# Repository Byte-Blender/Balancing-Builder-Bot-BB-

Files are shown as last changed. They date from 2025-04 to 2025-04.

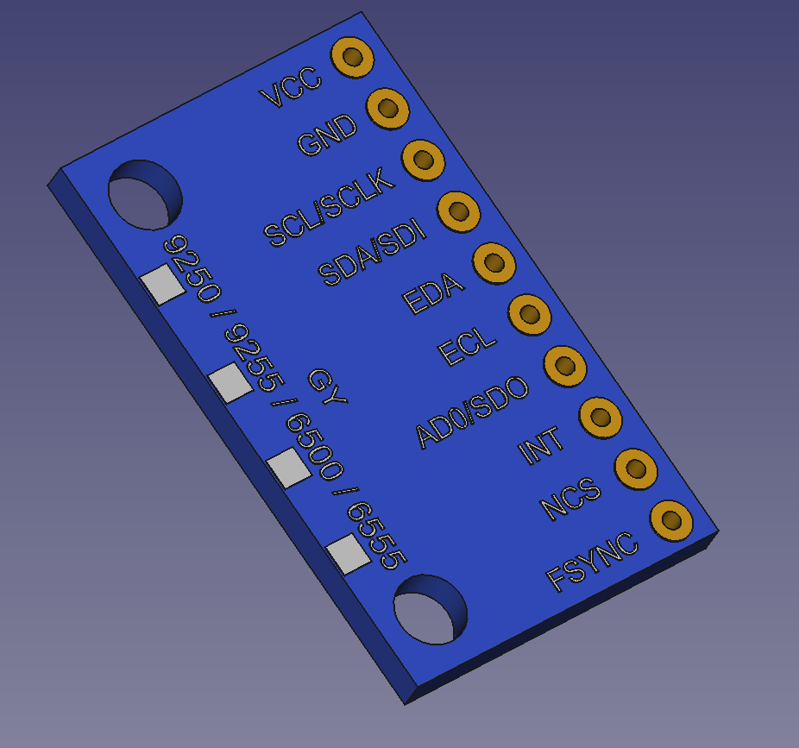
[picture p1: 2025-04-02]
Design files/Full Robot Assembly/Electronics/module-mpu-92-65-1.snapshot.3/mpu9250_bot.png

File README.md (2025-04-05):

# 🤖 Project Documentation: Balancing Builder Bot

**Team ID:** 2286  
**Author List:** Vidhi Singh Rajput, Shreyansh Gupta, Shreyas Rathore, Udit Nayak  
**Theme:** Balancing Builder Bot  
**Competition:** e-Yantra Robotics Competition (eYRC) 2024-25  

---

<h2>🏁 1. Competition Context</h2>

This project is developed as part of the prestigious <strong>e-Yantra Robotics Competition (eYRC)</strong> 2024-25, organized by <strong>IIT Bombay</strong>, under the theme “<em>Balancing Builder Bot</em>”.

e-Yantra is a national-level robotics competition that encourages innovation in embedded systems and robotics by solving real-world problems using hardware-software co-design. The Balancing Builder Bot theme challenges participants to build a robot that:

<ul>
  <li>Balances autonomously using control algorithms</li>
  <li>Navigates to specific checkpoints</li>
  <li>Picks and places objects using a robotic arm</li>
  <li>Interprets and acts on commands in real time</li>
</ul>

This documentation and code reflect our implementation for <strong>Task 2A</strong>, which involves combining balancing control with object manipulation using a pick-and-place arm.

---

## 🧠 2. Project Overview

The Balancing Builder Bot is a two-wheeled self-balancing robot that uses a combination of sensors, motors, control systems, and communication protocols to:

- Maintain an upright posture like an inverted pendulum  
- Move forward/backward based on user commands  
- Pick up and place objects using a servo-based robotic arm  
- Communicate via Bluetooth with external controllers  

---

## 🔧 3. Hardware Components

- **Microcontroller:** Arduino Uno/Nano  
- **IMU Sensor:** MPU6050 (accelerometer + gyroscope)  
- **DC Motors with Encoders** (for feedback)  
- **Servo Motors:** 2 (for arm and gripper control)  
- **Bluetooth Module:** HC-05  
- **Motor Driver Module:** L298N or equivalent  
- **Power Supply:** Battery Pack (7.4V or 11.1V Li-ion)  
- **Chassis:** Custom two-wheeled bot frame with mount for arm  

---

## 📦 4. Software and Libraries

- **Platform:** Arduino IDE  
- **Libraries Used:**
  - `MPU6050_light.h`
  - `Wire.h`
  - `Servo.h`
  - `SoftwareSerial.h`

---

## 🔁 5. Key Functionalities

### 🤖 a. Self-Balancing Using PID

- Reads tilt angle from MPU6050  
- Calculates PID output to control motor speed/direction  
- Maintains upright balance  

### 🧭 b. Position Control

- Uses wheel encoder feedback  
- Enables precise movement forward/backward  

### 💡 c. Bluetooth Command Interface

- Receives instructions like `forward`, `balance`, `arm_up`, `grip_close` etc.  
- Parses commands to trigger corresponding robot actions  

### 🛠 d. Pick and Place Arm

- Gripper and arm are controlled via servos  
- Smooth transition between positions using `moveServo()`  

---

## ⚙️ 6. Control Systems

- **Angle PID:** Keeps the robot upright  
- **Position PID:** Adds positional correction while in motion  
- **Encoder ISR:** Interrupt-driven wheel rotation tracking  

---

## 📡 7. Communication

- **Bluetooth (HC-05)** is used for wireless control  
- `SoftwareSerial` is mapped to analog pins A0 (TX) and A1 (RX)  
- The bot continuously checks for serial commands every 50 ms  

---

## 🧪 8. Testing and Evaluation

- Robot is tested in **CoppeliaSim simulation** first (if available)  
- Calibrated and tuned PID values on physical hardware  
- Passed Task 2A evaluation for:
  - Maintaining balance  
  - Successful pick-and-place  
  - Keyboard-controlled forward/backward navigation  

---

## 🚀 9. Sample Command Flow

1. Robot starts and balances  
2. Bluetooth sends `forward` → Robot moves forward  
3. `arm_down` + `grip_close` → Picks object  
4. `arm_up` → Lifts object  
5. `backward` → Moves to drop zone  
6. `arm_down` + `grip_open` → Drops object  
7. `balance` → Returns to balancing state  

---

## ⚠️ 10. Limitations & Future Scope

- **MPU6050** can be noisy; applying complementary/Kalman filter could improve results  
- **Encoder accuracy** depends on mechanical alignment  
- **State machine** implementation can make behavior more modular  
- Could be extended with **autonomous navigation** using vision or line-following sensors  

---

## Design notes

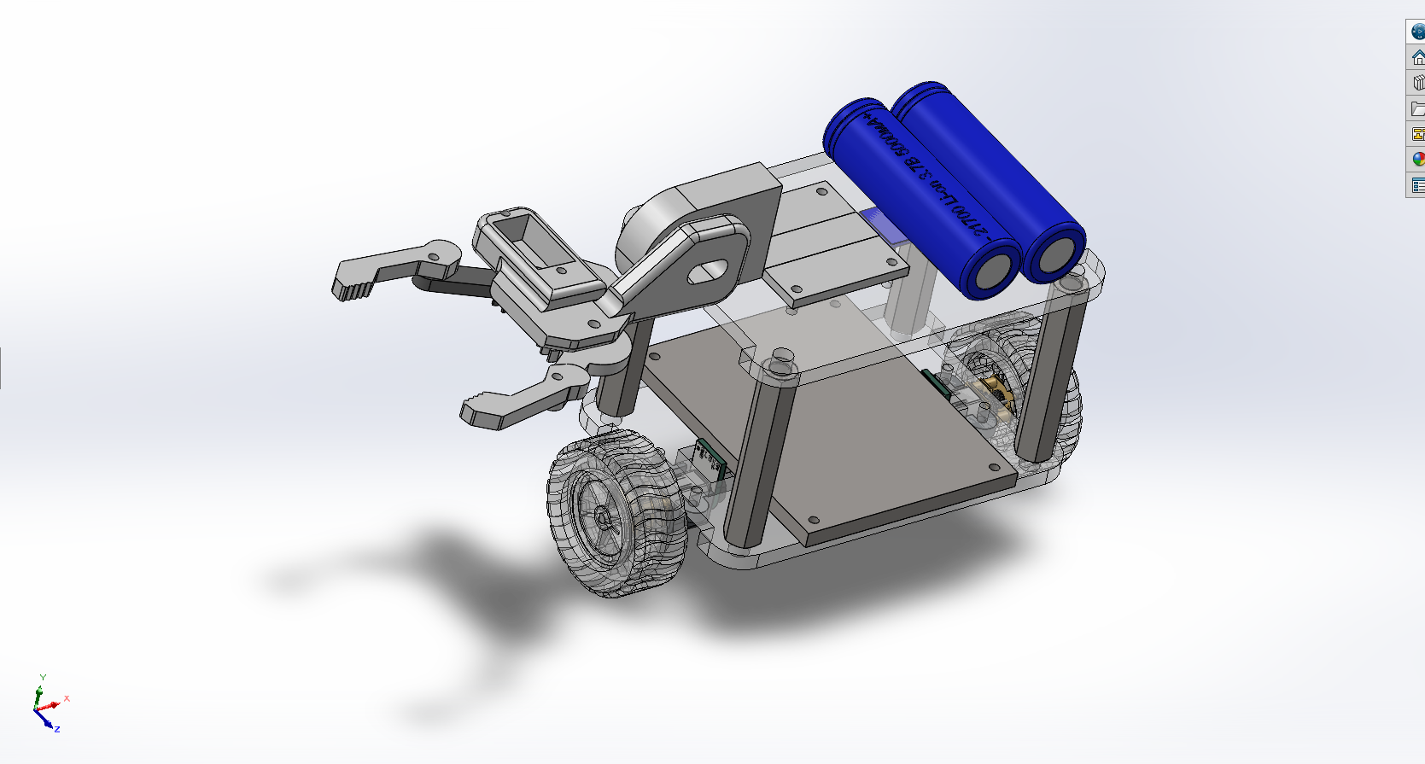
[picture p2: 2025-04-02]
Design files/Screenshot 2025-04-02 233240.png

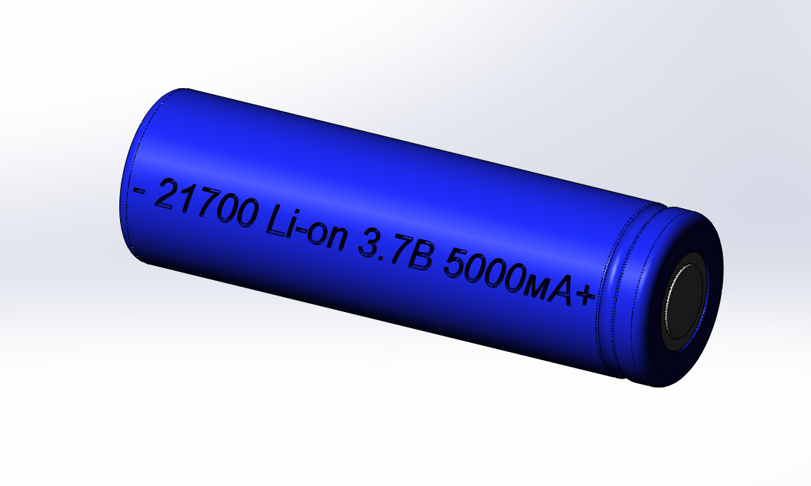
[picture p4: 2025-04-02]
Design files/Full Robot Assembly/Electronics/21700-3-7-5000-1.snapshot.2/Элемент 21700.png

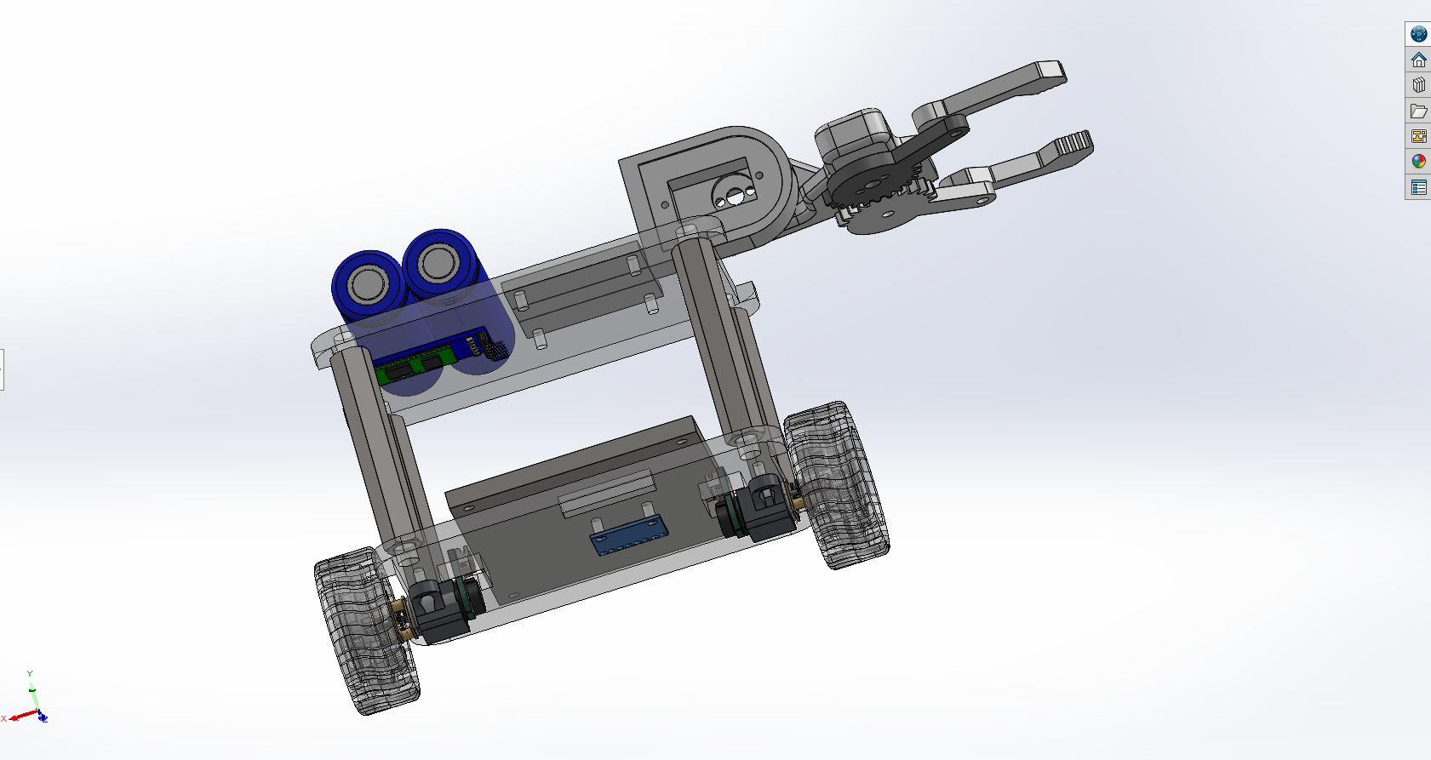
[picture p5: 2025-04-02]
Design files/Screenshot 2025-04-02 233254.png

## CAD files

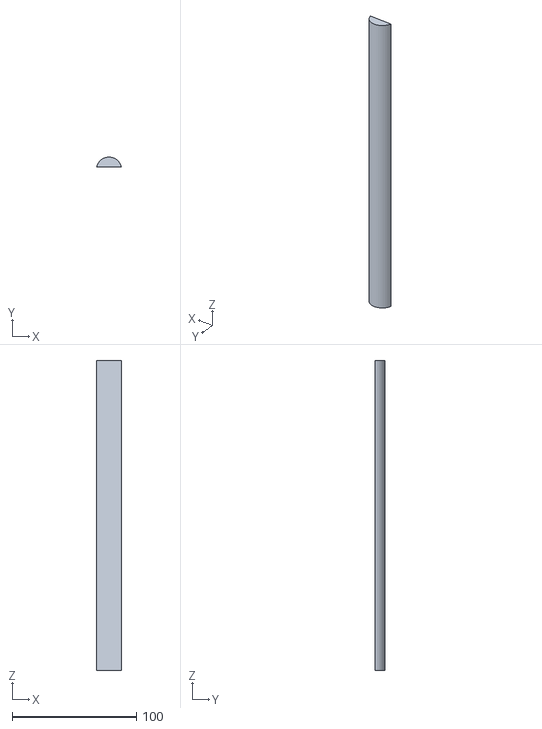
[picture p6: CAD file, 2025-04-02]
Design files/Arena Obstacles/cut/ramp_obstacle.stl
20.0 x 8.00 x 250.0

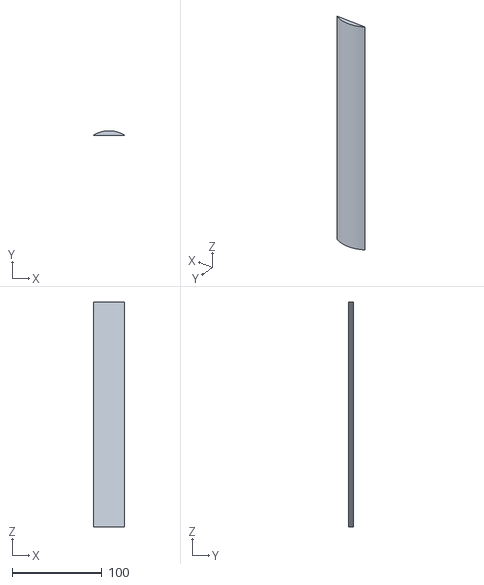
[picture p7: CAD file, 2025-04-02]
Design files/Arena Obstacles/Obstacle_1.stl
35.0 x 5.00 x 250.0

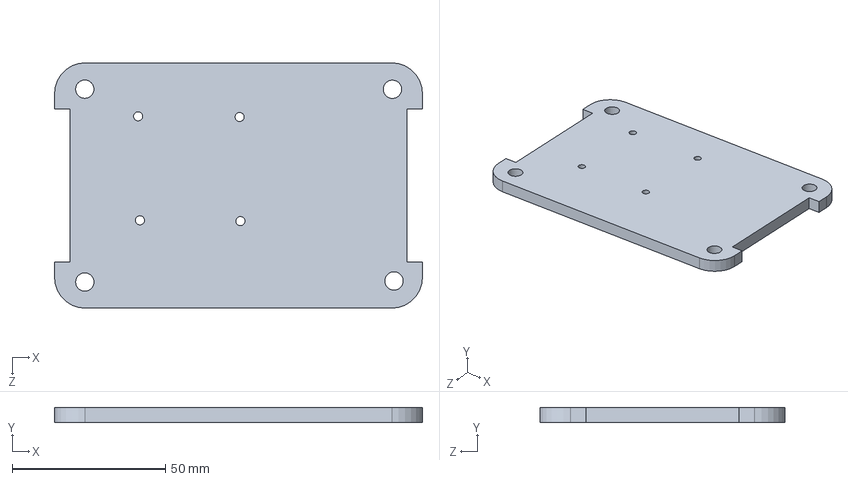
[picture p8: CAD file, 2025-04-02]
Design files/Full Robot Assembly/Body/top.SLDPRT
120.0 x 5.00 x 80.0 mm

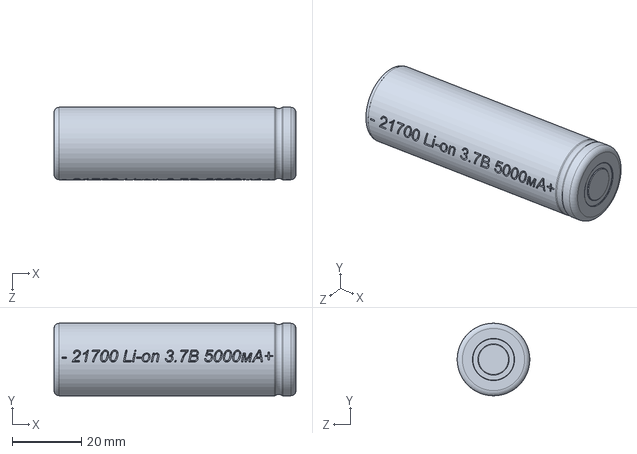
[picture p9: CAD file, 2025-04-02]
Design files/Full Robot Assembly/Electronics/21700-3-7-5000-1.snapshot.2/46.1. Элемент АКБ 21700 Li-ion 3.7В 5000мА 9.8А.SLDPRT
70.0 x 21.0 x 21.0 mm

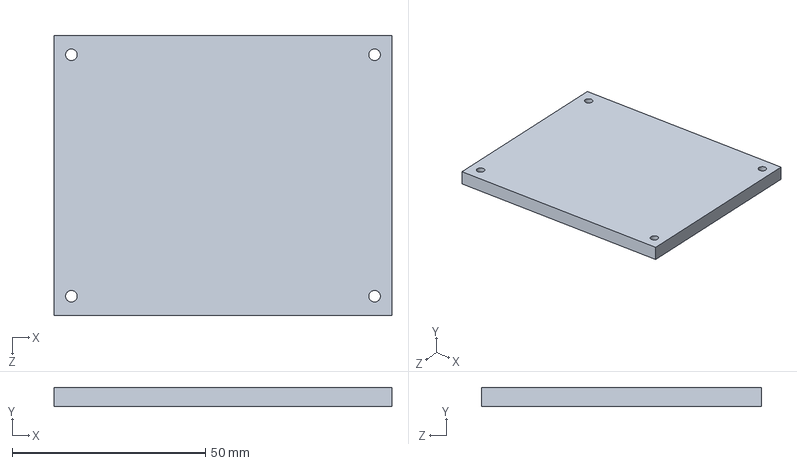
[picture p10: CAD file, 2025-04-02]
Design files/Full Robot Assembly/Electronics/bbpcb.SLDPRT
87.5 x 5.00 x 72.5 mm

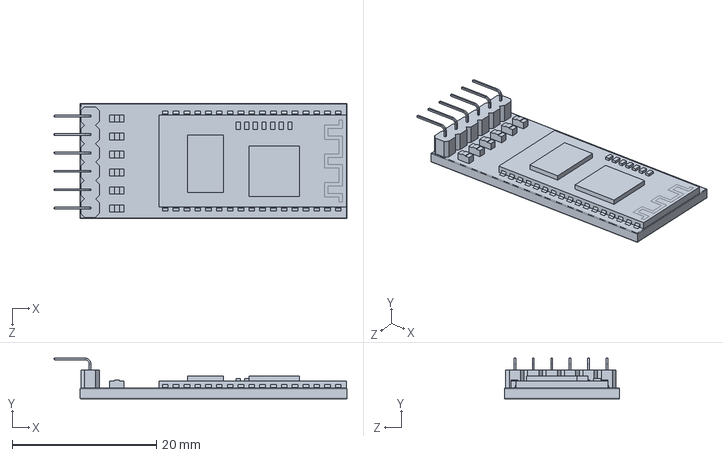
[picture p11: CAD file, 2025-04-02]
Design files/Full Robot Assembly/Electronics/hc05-bluetooth-module-1.snapshot.1/HC05.STEP
40.6 x 5.67 x 16.0 mm

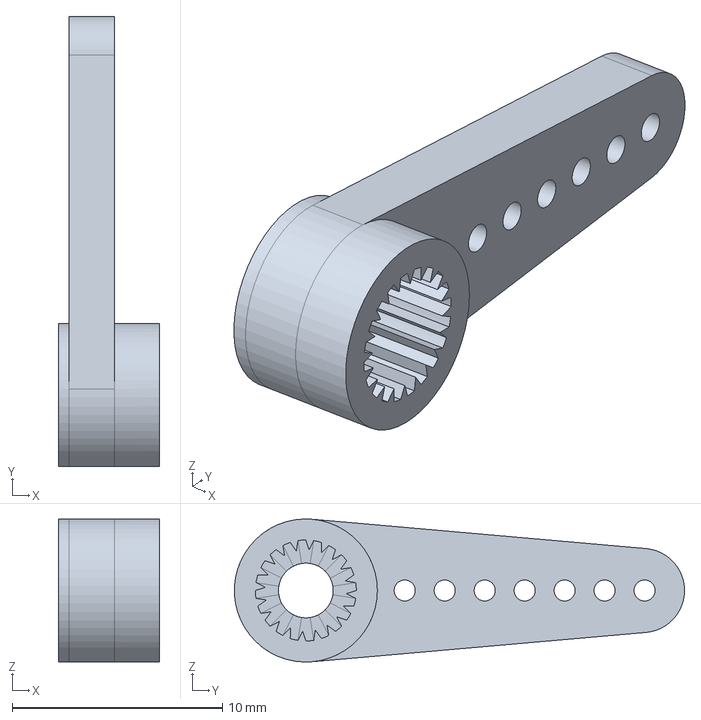
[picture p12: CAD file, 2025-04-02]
Design files/Full Robot Assembly/Electronics/mg90s-micro-servo-2.snapshot.3/mg90_ali/MG90S_bras_01.FCStd
4.80 x 21.4 x 6.80 mm

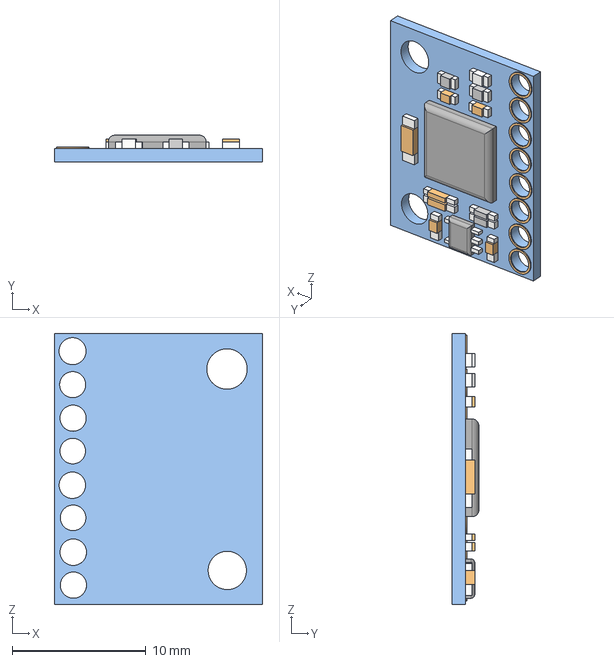
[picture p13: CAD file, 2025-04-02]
Design files/Full Robot Assembly/Electronics/mpu6050-8.snapshot.1/MPU6050 v2.step
15.6 x 2.00 x 20.3 mm

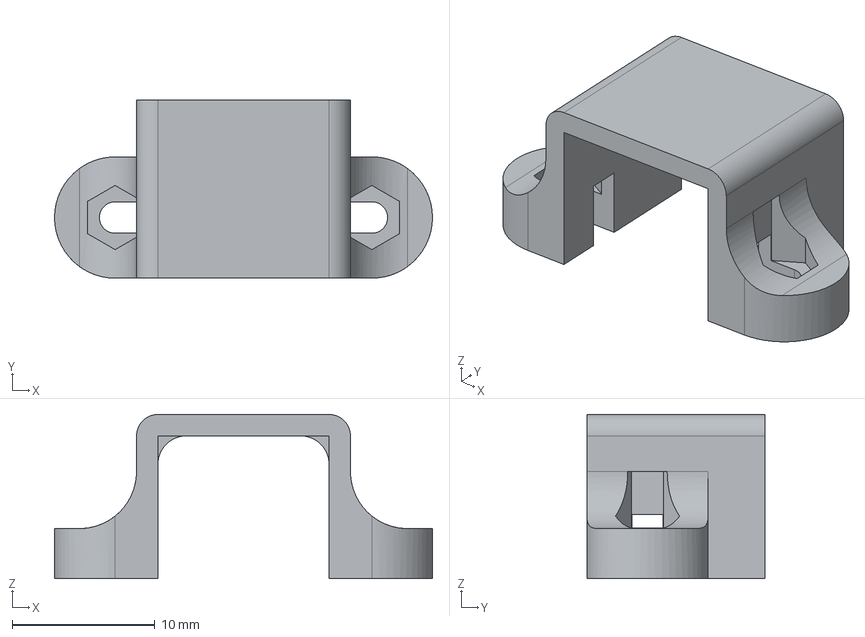
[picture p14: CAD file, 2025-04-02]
Design files/Full Robot Assembly/Electronics/n20-motor-mount-2.snapshot.1/motor mount-Body.step
26.5 x 12.5 x 11.5 mm

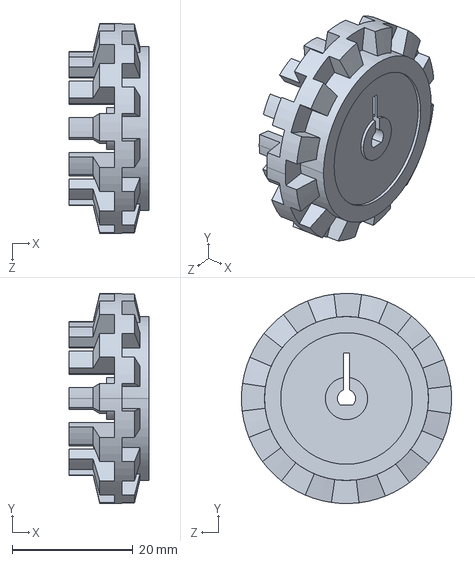
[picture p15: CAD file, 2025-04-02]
Design files/Full Robot Assembly/Electronics/n20-wheel-d43-mm-1.snapshot.2/N20 Wheel Velg D43 mm.STEP
13.2 x 34.7 x 34.8 mm

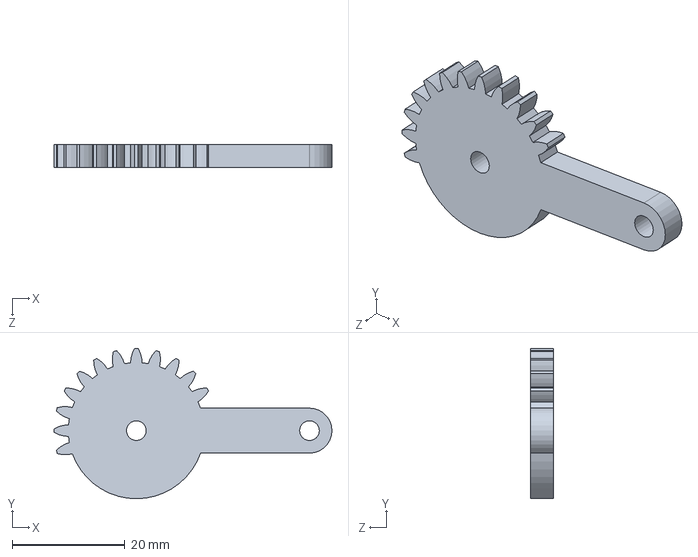
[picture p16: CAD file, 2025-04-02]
Design files/Full Robot Assembly/Gripper/Part 2 gear 2.SLDPRT
49.4 x 26.7 x 4.00 mm

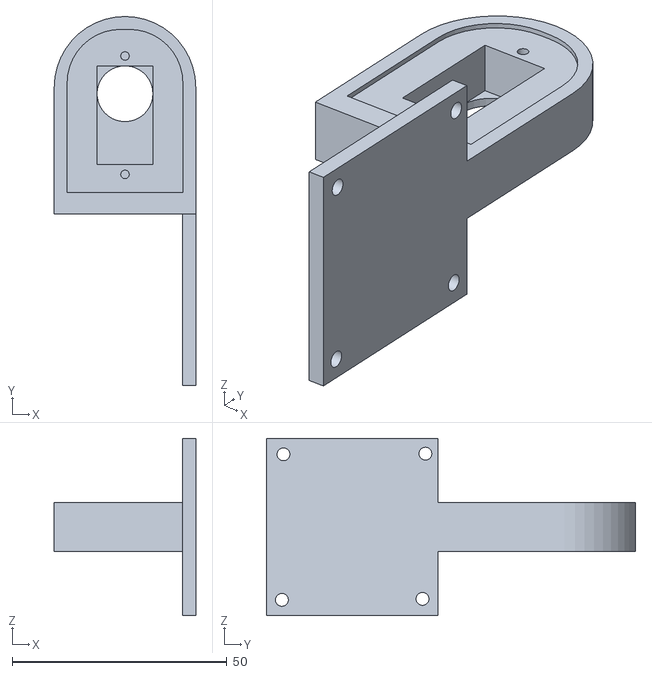
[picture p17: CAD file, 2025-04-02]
Design files/self balancing robot 3D print and cut/armConnector/armConnector.STL
33.0 x 86.0 x 41.4

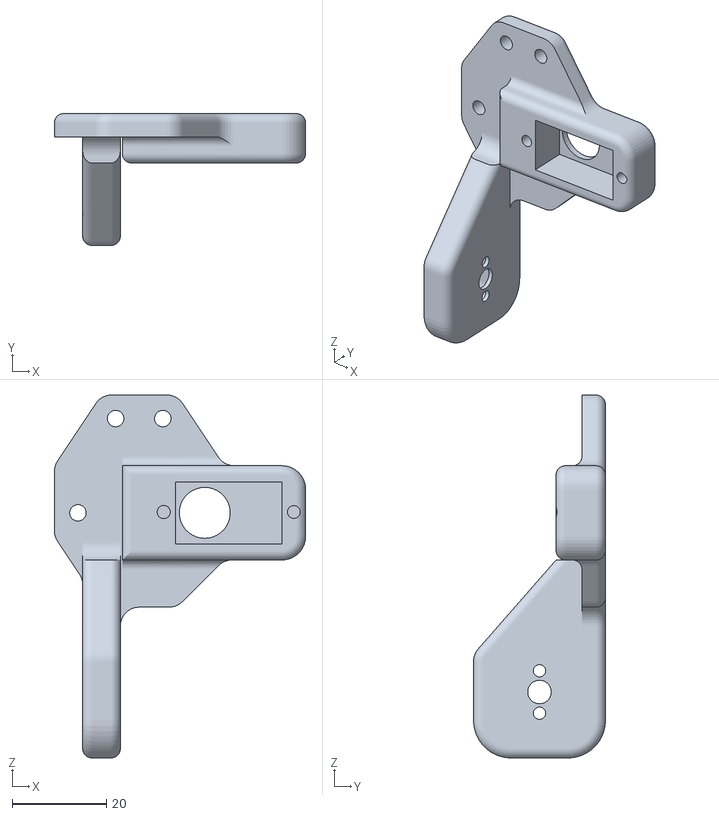
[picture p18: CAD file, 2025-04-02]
Design files/self balancing robot 3D print and cut/gripper base/Gripper_Base.STL
53.3 x 28.0 x 77.0

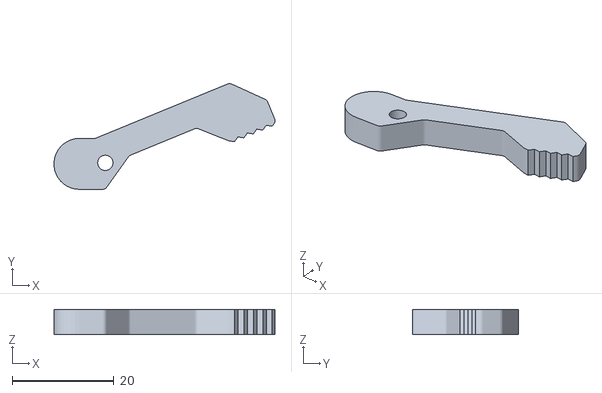
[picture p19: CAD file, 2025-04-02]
Design files/self balancing robot 3D print and cut/gripper2/Gripper2.STL
43.3 x 20.7 x 5.00

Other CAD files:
Design files/Full Robot Assembly/Electronics/mg90s-micro-servo-2.snapshot.3/Assem1.SLDASM
Design files/Full Robot Assembly/Electronics/mg90s-micro-servo-2.snapshot.3/MG90S_arm01.step
Design files/self balancing robot 3D print and cut/laser cutting files/base5mm.DXF
Design files/Arena Obstacles/cut/ramp_board.DXF
Design files/Arena Obstacles/ramp_obstacle.SLDPRT
Design files/Full Robot Assembly/Body/base.SLDPRT
Design files/Full Robot Assembly/Electronics/hc05-bluetooth-module-1.snapshot.1/HC05.SLDPRT
Design files/Full Robot Assembly/Electronics/hexagonal_spacer_FF_M6_H60_HEX10_FTD12.step
Design files/Full Robot Assembly/Electronics/mg90s-micro-servo-2.snapshot.3/mg90_ali/M90S_ali.FCStd
Design files/Full Robot Assembly/Electronics/mg90s-micro-servo-2.snapshot.3/mg90_ali/mg90s_with_arm.FCStd
Design files/Full Robot Assembly/Electronics/mpu6050-8.snapshot.1/MPU6050 v2.stl
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

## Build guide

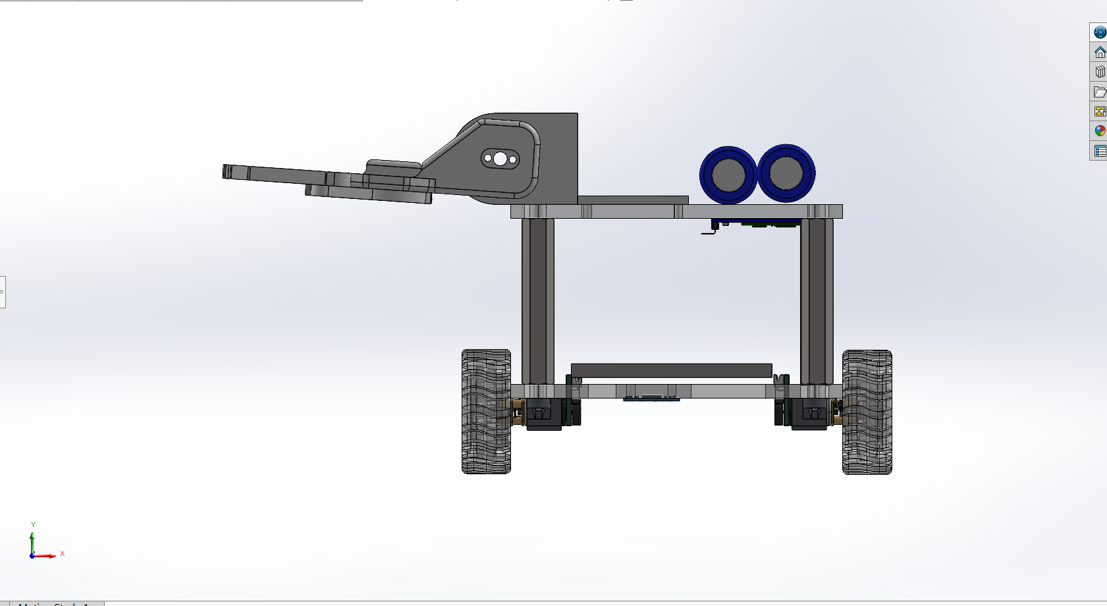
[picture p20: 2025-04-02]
Design files/Full Robot Assembly/assembly/Screenshot 2025-04-02 233211.png

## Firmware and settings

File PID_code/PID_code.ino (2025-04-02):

/*
 * Team Id: 2286
 * Author List: Vidhi Singh Rajput, Shreyansh Gupta, Shreyas Rathore, Udit Nayak
 * Filename: robot_control.c
 * Theme: Balancing Builder Bot
 * Functions: moveServo, Grip_close, Grip_open, arm_down, arm_up, forward, backward, balance, 
 *            mot_rencoder_left, mot_rencoder_right, controlMotor1, controlMotor2, setup, loop
 * Global Variables: mpu, gripservo, armservo, accX_offset, accY_offset, accZ_offset,
 *                   gyroX_offset, gyroY_offset, gyroZ_offset, inputPin1, inputPin2, inputPin3,
 *                   inputPin4, EN1, EN2, wheel_pulse_count_left, wheel_pulse_count_right,
 *                   wheel_distance_left, wheel_distance_right, Balance_flag, Kp_balance,
 *                   Ki_balance, Kd_balance, Kp_position, Ki_position, Kd_position, setPoint,
 *                   currentAngle, error, lastError, integral, derivative, output,
 *                   positionSetPoint, currentPosition, positionError, lastPositionError,
 *                   positionIntegral, positionDerivative, positionOutput, previousBTTime,
 *                   BTInterval, previousMPUTime, MPUInterval, wheel_radius, pulses_per_revolution.
 */

#include <MPU6050_light.h>
#include <SoftwareSerial.h>
#include <Wire.h>
#include <Servo.h>

// Define SoftwareSerial pins
SoftwareSerial bluetooth(A1, A0);  // RX, TX

//Mpu and Servo intialisation
MPU6050 mpu(Wire);
Servo gripservo;
Servo armservo;

// Pre-determined offsets for MPU6050
const int accX_offset = 0.01;
const int accY_offset = -0.01;
const int accZ_offset = -0.11;
const int gyroX_offset = -2.26;
const int gyroY_offset = 0.90;
const int gyroZ_offset = -0.99;

// Motor pins
const int inputPin1 = A2;
const int inputPin2 = A3;
const int inputPin3 = 9;
const int inputPin4 = 4;
const int EN1 = 6;
const int EN2 = 5;
float combinedOutput = 0;

// Encoder Pins
#define encodPinAR 7
#define encodPinBR 2
#define encodPinAL 8
#define encodPinBL 3

// Balance control flag
int Balance_flag = 0;

// PID Parameters
float Kp_balance = 61.39, Ki_balance = 750, Kd_balance = 1.55;
float Kp_position = 200, Ki_position = 0, Kd_position = 0;

// PID variables
float setPoint = 0.0, currentAngle = 0.0;
float error = 0.0, lastError = 0.0;
float integral = 0.0, derivative = 0.0, output = 0.0;

// Position PID variables
float positionSetPoint = 0.0, currentPosition = 0.0;
float positionError = 0.0, lastPositionError = 0.0;
float positionIntegral = 0.0, positionDerivative = 0.0, positionOutput = 0.0;

// Timing variables for Bluetooth processing in ms
unsigned long previousBTTime = 0;
const unsigned long BTInterval = 50;
// Timing variables for MPU processing in ms
unsigned long previousMPUTime = 0;
const unsigned long MPUInterval = 10;

// Constants
const float wheel_radius = 0.043; //43mm radius in meters
const int pulses_per_revolution = 300;

// Position control variables
volatile int wheel_pulse_count_left = 0, wheel_pulse_count_right = 0;
float wheel_distance_left = 0.0, wheel_distance_right = 0.0;

/*
 * Function Name: moveServo
 * Input: Servo object reference, targetAngle (int), stepDelay (int, optional)
 * Output: None
 * Logic: Gradually moves the servo to the target position with smooth motion.
 * Example Call: moveServo(gripservo, 90);
 */
void moveServo(Servo &servo, int targetAngle, int stepDelay = 15) {
  int currentAngle = servo.read();
  if (currentAngle < targetAngle) {
    for (int angle = currentAngle; angle <= targetAngle; angle++) {
      servo.write(angle);
      delay(stepDelay);
    }
  } else {
    for (int angle = currentAngle; angle >= targetAngle; angle--) {
      servo.write(angle);
      delay(stepDelay);
    }
  }
}

/* 
 * Function Name: Grip_close
 * Input: None
 * Output: None
 * Logic: Closes the grip by moving the servo to the specified angle.
 * Example Call: Grip_close();
 */
void Grip_close() {
  armservo.detach();
  gripservo.attach(11);
  gripservo.write(85);
}

/* 
 * Function Name: Grip_open
 * Input: None
 * Output: None
 * Logic: Open the grip by moving the servo to the specified angle.
 * Example Call: Grip_close();
 */
void Grip_open() {
  armservo.detach();
  gripservo.attach(11);
  gripservo.write(130);
}

/* 
 * Function Name: arm_up
 * Input: None
 * Output: None
 * Logic: Move the arm up by moving the servo to the specified angle.
 * Example Call: arm_up();
 */
void arm_up() {
  gripservo.detach();
  armservo.attach(13);
  armservo.write(90);
}

/* 
 * Function Name: arm_down
 * Input: None
 * Output: None
 * Logic: MOve the arm down by moving the servo to the specified angle.
 * Example Call: arm_down();
 */
void arm_down() {
  gripservo.detach();
  armservo.attach(13);
  armservo.write(150);
}

/* 
 * Function Name: forward
 * Input: None
 * Output: None
 * Logic: Change the setpoint of MPU to specified value so that it moves forward.
 * Example Call: forward();
 */
void forward() {
  setPoint = 0.8;
  Kp_position = 0;
}

/* 
 * Function Name: backward
 * Input: None
 * Output: None
 * Logic: Change the setpoint of MPU to specified value so that it moves backward.
 * Example Call: backward();
 */
void backward() {
  setPoint = -1.5;
  Kp_position = 0;
}

/* 
 * Function Name: balance
 * Input: None
 * Output: None
 * Logic: Change the setpoint of MPU to 0 so that it balances on its present position.
 * Example Call: balance();
 */
void balance() {
  setPoint = 0;
  armservo.detach();
  gripservo.detach();
}

/* 
 * Function Name: mot_rencoder_left
 * Input: None
 * Output: None
 * Logic: Increments or decrements wheel_pulse_count_left based on the phase difference between encodPinAL and encodPinBL.
 * Example Call: mot_rencoder_left();
 */
void mot_rencoder_left() {
  if (digitalRead(encodPinBL) > digitalRead(encodPinAL)) {
    wheel_pulse_count_left++;
  } else {
    wheel_pulse_count_left--;
  }
}

/* 
 * Function Name: mot_rencoder_right
 * Input: None
 * Output: None
 * Logic: Increments or decrements wheel_pulse_count_right based on encodPinAR and encodPinBR.
 * Example Call: mot_rencoder_right();
 */
void mot_rencoder_right() {
  if (digitalRead(encodPinBR) > digitalRead(encodPinAR)) {
    wheel_pulse_count_right--;
  } else {
    wheel_pulse_count_right++;
  }
}

/* 
 * Function Name: controlMotor1
 * Input: pidOutput
 * Output: None
 * Logic: Rotate the motor clockwise or anti-clockwise based on pid output.
 * Example Call: controlMotor1(255);
 */
void controlMotor1(float pidOutput) {
  if (pidOutput > 0) {
    digitalWrite(inputPin1, HIGH);
    digitalWrite(inputPin2, LOW);
    analogWrite(EN1, pidOutput);
  } else {
    pidOutput = abs(pidOutput);
    digitalWrite(inputPin1, LOW);
    digitalWrite(inputPin2, HIGH);
    analogWrite(EN1, pidOutput);
  }
}

/* 
 * Function Name: controlMotor2
 * Input: pidOutput
 * Output: None
 * Logic: Rotate the motor clockwise or anti-clockwise based on pid output.
 * Example Call: controlMotor2(255);
 */
void controlMotor2(float pidOutput) {
  if (pidOutput > 0) {
    digitalWrite(inputPin3, LOW);
    digitalWrite(inputPin4, HIGH);
    analogWrite(EN2, pidOutput);
  } else {
    pidOutput = abs(pidOutput);
    digitalWrite(inputPin3, HIGH);
    digitalWrite(inputPin4, LOW);
    analogWrite(EN2, pidOutput);
  }
}

/*
 * Function Name: setup
 * Input: None
 * Output: None
 * Logic: Initializes the sensors, motors, servos and Bluetooth communication.
 * Example Call: setup();
 */
void setup() {
  Serial.begin(9600);
  Wire.begin();

  // Initialize MPU6050
  byte status = mpu.begin();
  if (status != 0) {
    while (1)
      ;  //Stops if intialization fails.
  }

  //Set the pretermined offset values for accelerometer and gyroscope (for MPU6050).
  mpu.setAccOffsets(accX_offset, accY_offset, accZ_offset);
  mpu.setGyroOffsets(gyroX_offset, gyroY_offset, gyroZ_offset);

  // Motor pin configurations
  pinMode(inputPin1, OUTPUT);
  pinMode(inputPin2, OUTPUT);
  pinMode(inputPin3, OUTPUT);
  pinMode(inputPin4, OUTPUT);

  bluetooth.begin(9600);  // For HC-05 (default baud rate is 9600).

  //Intialization of encoder
  pinMode(8, INPUT_PULLUP);
  pinMode(3, INPUT_PULLUP);
  attachInterrupt(digitalPinToInterrupt(3), mot_rencoder_left, RISING);
  pinMode(7, INPUT_PULLUP);
  pinMode(2, INPUT_PULLUP);
  attachInterrupt(digitalPinToInterrupt(2), mot_rencoder_right, RISING);
}

/*
 * Function Name: loop
 * Input: None
 * Output: None
 * Logic: Runs the main control loop, processes MPU6050 data, computes PID, and executes Bluetooth commands.
 * Example Call: loop();
 */
void loop() {
  unsigned long currentTime = millis();  //millis() returns the time elapsed since the program started.

  if (currentTime - previousMPUTime >= MPUInterval) {
    previousMPUTime = currentTime;  //Updates previousMPUTime to keep track of the last execution.

    // Update MPU6050 readings
    mpu.update();
    currentAngle = mpu.getAngleX();  // Get current angle (pitch)

    wheel_distance_left = (wheel_pulse_count_left / float(pulses_per_revolution)) * 2 * PI * wheel_radius;
    wheel_distance_right = (wheel_pulse_count_right / float(pulses_per_revolution)) * 2 * PI * wheel_radius;
    currentPosition = (wheel_distance_left + wheel_distance_right) / 2.0;  //currentPosition is the average distance traveled by both wheels.

    if (Balance_flag == 0) {
      error = positionSetPoint - currentAngle;                        //Computes tilt error.
      integral += error * 0.01;                                       // 10 ms = 0.01 s
      integral = constrain(integral, -50, 50);                        // Prevent windup
      derivative = (error - lastError) / 0.01;                        //calculates the rate of error change.
      float I = Ki_balance * integral;                                //accumulates error over time (preventing drift).
      output = (Kp_balance * error) + I + (Kd_balance * derivative);  //output is the control signal (motor speed adjustment).
      output = constrain(output, -255, 255);                          //limits output to motor speed range.
      lastError = error;
    } else if (Balance_flag == 1) {
      error = setPoint - currentAngle;
      integral += error * 0.01;                 // 10 ms = 0.01 s
      integral = constrain(integral, -50, 50);  // Prevent windup
      derivative = (error - lastError) / 0.01;
      float I = Ki_balance * integral;
      output = (Kp_balance * error) + I + (Kd_balance * derivative);
      output = constrain(output, -255, 255);
      lastError = error;
    }

    // Position PID Calculations: Uses a second PID controller to regulate position based on currentPosition and controls how far the bot has moved, preventing unintended drifts.
    positionError = positionSetPoint - currentPosition;
    positionIntegral += positionError * 1;
    positionIntegral = constrain(positionIntegral, -50, 50);
    positionDerivative = (positionError - lastPositionError) / 0.01;
    positionOutput = (Kp_position * positionError) + (Ki_position * positionIntegral) + (Kd_position * positionDerivative);
    positionOutput = constrain(positionOutput, -50, 50);
    lastPositionError = positionError;

    //The final motor speed is determined by adding balance (output) and position (positionOutput) and Ensures motor speed stays within safe limits.
    float combinedOutput = output + positionOutput;
    combinedOutput = constrain(combinedOutput, -255, 255);

    //Sends the final computed signal to both motors to maintain balance and position.
    controlMotor1(combinedOutput);
    controlMotor2(combinedOutput);
  }
  char bt_command = 'X';

  if (bluetooth.available()) {
    char bt_command = bluetooth.read();
    //'N' → Lowers the robot's arm.
    //'n' → Raises the arm.
    //'M' → Closes the gripper.
    //'m' → Opens the gripper.
    //'F' → Moves forward.
    //'B' → Moves backward.
    //'L' and 'R' adjust motor outputs to turn left and right.
    if (bt_command == 'N') {
      arm_down();
    } else if (bt_command == 'n') {
      arm_up();
    } else if (bt_command == 'M') {
      Grip_close();
    } else if (bt_command == 'm') {
      Grip_open();
    } else if (bt_command == 'F') {
      forward();
    } else if (bt_command == 'B') {
      backward();
    }
    //Loop is used to ensure continuous movement in left and right direction.
    else if (bt_command == 'L') {
      for (int i = 0; i <= 150; i++) {
        controlMotor1(combinedOutput);
        controlMotor2(combinedOutput - 250);
      }
    } else if (bt_command == 'R') {
      for (int i = 0; i <= 150; i++) {
        controlMotor1(combinedOutput - 250);
        controlMotor2(combinedOutput);
      }
    }
    //'S' → Calls balance() (rebalances the robot).
    //'Y' → Sets setPoint to 1.5 (adjusts balance threshold) to increase speed whenever required.
    //'X' → Sets setPoint to -1.5 (adjusts balance threshold differently) to decrease speed whenever required.
    //'J' → Plays a buzzer sound on pin 12 at 1000 Hz for 1 seconds.

    else if (bt_command == 'S') {
      balance();
    } else if (bt_command == 'Y') {
      setPoint = 1.5;
    } else if (bt_command == 'X') {
      setPoint = -1.5;
    } else if (bt_command == 'J') {
      tone(12, 1000, 1000);
    }
  }
}

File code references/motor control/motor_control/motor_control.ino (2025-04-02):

const int inputPin1  = A2;    // Pin 15 of L293D IC
const int inputPin2  = A3;    // Pin 10 of L293D IC
                              //Motor B
const int inputPin3  = 9;    // Pin  7 of L293D IC
const int inputPin4  = 4;    // Pin  2 of L293D IC
int EN1 = 6;                 // Pin 1 of L293D IC
int EN2 = 5;

int forwardMove(){
  digitalWrite(inputPin1, HIGH);
   digitalWrite(inputPin2, LOW);
   digitalWrite(inputPin3, LOW);
   digitalWrite(inputPin4, HIGH);
}

int backwardMove(){
  digitalWrite(inputPin1, LOW);
   digitalWrite(inputPin2, HIGH);
   digitalWrite(inputPin3, HIGH);
   digitalWrite(inputPin4, LOW);
}

void setup() {
    pinMode(EN1, OUTPUT);   // where the motor is connected to
   pinMode(EN2, OUTPUT);   // where the motor is connected to
   pinMode(inputPin1, OUTPUT);
   pinMode(inputPin2, OUTPUT);
   pinMode(inputPin3, OUTPUT);
   pinMode(inputPin4, OUTPUT);
   analogWrite(EN1, 200);      //sets the motors speed
   analogWrite(EN2, 200);

}


void loop() {
   delay(500);
   tone(12, 2000);
   delay(100);
   noTone(12);

  //  ONE DIRECTION
   forwardMove();
   delay(200);

  //  OPPOSITE DIRECTION
   
   //delay(200);

}
